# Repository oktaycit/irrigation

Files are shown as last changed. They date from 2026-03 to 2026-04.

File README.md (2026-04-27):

# 🌿 STM32F407VET6 Sulama Sistemi

pH ve EC kontrollu, 8 parsel vanali, iki farkli musteri segmentine hizmet eden dinamik ihtiyac odakli otomatik sulama kontrol sistemi.

---

## 📋 İçindekiler

- [Özellikler](#özellikler)
- [Donanım](#donanım)
- [Yazılım Mimarisi](#yazılım-mimarisi)
- [Klasör Yapısı](#klasör-yapısı)
- [Kurulum](#kurulum)
- [Kullanım](#kullanım)
- [Dokümantasyon](#dokümantasyon)
- [AI Model Stratejisi](#ai-model-stratejisi)

---

## ✨ Özellikler

### Ana Özellikler
- ✅ **3.2" TFT Dokunmatik LCD** - 320x240 QVGA, ILI9341 driver
- ✅ **pH Kontrolü** - 0-14 pH ölçüm aralığı, otomatik dozaj
- ✅ **EC Kontrolü** - 0-20 mS/cm ölçüm aralığı, otomatik dozaj
- ✅ **8 Kanal Vana Kontrolü** - Multi-zone, parsel bazlı sulama
- ✅ **Hibrit Sulama Tetikleme** - Basit modda periyot, pro modda isik/sensor odakli karar
- ✅ **3 Fazli Sulama Akisi** - Pre-flush, dosing, post-flush
- ✅ **Iki Urun Seviyesi** - Dusuk maliyetli ciftci surumu ve ileri seviye isletme surumu
- ✅ **Otomatik/Manuel Mod** - Esnek çalışma modları
- ✅ **EEPROM Veri Saklama** - Parametre ve log kayıtları
- ✅ **Kalibrasyon** - Çok noktalı pH/EC kalibrasyonu

### Güvenlik Özellikleri
- 🛡️ Sensör hata algılama
- 🛡️ Vana sıkışma koruması
- 🛡️ Ölü bant (hysteresis) kontrolü
- 🛡️ Watchdog timer
- 🛡️ Acil durum durdurma

---

## 🔌 Donanım

### Ana Bileşenler
| Bileşen | Model/Özellik |
|---|---|
| MCU | STM32F407VET6 (512KB Flash, 192KB RAM) |
| Display | 3.2" TFT LCD (ILI9341, FSMC) |
| Touch | XPT2046 Dirençli Dokunmatik |
| pH Sensörü | 0-14 pH Analog |
| EC Sensörü | 0-20 mS/cm Analog |
| Vana Sürücü | ULN2803 Darlington Array |
| EEPROM | 24C256 (32 KBit) |

### Pin Assignment Özeti
| Fonksiyon | STM32 Pinleri |
|---|---|
| FSMC LCD | PD0-PD15, PE0-PE15, PD4,PD5,PD7,PD11 |
| Touch SPI | PA5,PA6,PA7,PB10,PC15 |
| pH ADC | PA0 |
| EC ADC | PA1 |
| Vanalar | PB0-PB7 |
| I2C EEPROM | PB8,PB9 |
| Debug UART | PA9,PA10 |

Detaylı pin mapping için: [Docs/02_Pin_Assignment.md](Docs/02_Pin_Assignment.md)

---

## 🏗️ Yazılım Mimarisi

```
┌─────────────────────────────────────────────────┐
│              Kullanıcı Arayüzü (GUI)            │
│         (touch_xpt2046 + gui + lcd)             │
├─────────────────────────────────────────────────┤
│           Sulama Kontrol Algoritması            │
│            (irrigation_control)                 │
├──────────────┬─────────────────┬────────────────┤
│  pH Kontrol  │   EC Kontrol    │  Vana Kontrol  │
│  (sensors)   │  (sensors)      │  (valves)      │
├──────────────┴─────────────────┴────────────────┤
│              Sensör Sürücü Katmanı              │
├──────────────┬─────────────────┬────────────────┤
│  LCD Driver  │  Touch Driver   │  EEPROM        │
│(lcd_ili9341) │(touch_xpt2046)  │  (eeprom)      │
├──────────────┴─────────────────┴────────────────┤
│              HAL / LL Driver Katmanı            │
│              (STM32CubeMX generated)            │
└─────────────────────────────────────────────────┘
```

---

## 📁 Klasör Yapısı

```
irrigation/
├── Docs/                          # Dokümantasyon dosyaları
│   ├── 01_Sistem_Gereksinimleri.md
│   ├── 02_Pin_Assignment.md
│   └── 03_Donanim_Semasi.md
├── gateway/                       # Linux edge gateway ve yerel dashboard
│   ├── app.py
│   └── static/
├── stm32/                         # STM32 firmware projesi
│   ├── Core/
│   │   ├── Inc/                   # Header dosyaları
│   │   └── Src/                   # Kaynak dosyalar
│   ├── Drivers/                   # STM32 HAL/LL drivers (CubeMX)
│   ├── Middlewares/               # USB middleware ve harici kutuphaneler
│   ├── Makefile
│   └── STM32F407VETX_FLASH.ld
├── Makefile                       # Kökten STM32 build delegasyonu
└── README.md
```

---

## 🛠️ Kurulum

### 1. STM32CubeMX ile Proje Oluşturma

1. STM32CubeMX uygulamasını açın
2. STM32F407VET6 mikrodenetleyiciyi seçin
3. Aşağıdaki çevre birimlerini yapılandırın:

| Peripheral | Ayarlar |
|---|---|
| FSMC | 16-bit data, Bank1 NOR/SRAM |
| SPI1 | Full Duplex, 8-bit, Prescaler=64 |
| ADC1 | 2 channel scan mode (IN0, IN1) |
| I2C1 | 100/400 kHz |
| USART1 | 115200, 8N1 |
| TIM1 | PWM Generation CH1 (Backlight) |
| GPIO | PC15 as EXTI (Touch IRQ) |

4. Clock Configuration: 168 MHz (PLL kullanılarak)
5. Project Manager ile IDE seçin (Keil, IAR, STM32CubeIDE)
6. Generate Code

### 2. Oluşturulan Koda Entegrasyon

STM32CubeMX ile oluşturulan projeye `stm32/Core/Inc/` klasöründeki header dosyalarını ekleyin.

### 3. Derleme

IDE'niz ile projeyi derleyin:
```bash
# Kök dizinden
make -j4

# veya firmware dizininden
make -C stm32 -j4
```

### 4. Programlama

ST-Link veya J-Link ile MCU'ya flash edin:
```bash
# OpenOCD örneği
openocd -f interface/stlink.cfg -f target/stm32f4x.cfg -c "program firmware.elf verify reset exit"
```

---

## 📖 Kullanım

### Ana Ekran
```
┌─────────────────────────────────┐
│  pH: 6.5    EC: 1.8 mS/cm      │
│                                 │
│  Parsel 3 - Sulanıyor          │
│  ████████░░ 80%  02:30 kaldı   │
│                                 │
│  [Ana Menü] [Manuel] [Ayarlar] │
└─────────────────────────────────┘
```

### Menü Yapısı
```
ANA EKRAN
├── Ayarlar
│   ├── pH Hedef/Min/Max
│   ├── EC Hedef/Min/Max
│   └── Parsel Süreleri
├── Manuel Kontrol
│   └── Vana 1-8 Aç/Kapat
├── Kalibrasyon
│   ├── pH Kalibrasyon
│   └── EC Kalibrasyon
└── Sistem
    ├── Log Kayıtları
    └── Cihaz Bilgisi
```

---

## 📚 Dokümantasyon

| Dosya | Açıklama |
|---|---|
| [Docs/01_Sistem_Gereksinimleri.md](Docs/01_Sistem_Gereksinimleri.md) | Sistem gereksinimleri ve özellikler |
| [Docs/02_Pin_Assignment.md](Docs/02_Pin_Assignment.md) | STM32 pin mapping tablosu |
| [Docs/03_Donanim_Semasi.md](Docs/03_Donanim_Semasi.md) | Donanım bağlantı şemaları |
| [Docs/06_USB_Programlama_Protokolu.md](Docs/06_USB_Programlama_Protokolu.md) | USB ile program import/export komut seti |
| [Docs/07_USB_Masaustu_Arayuzu.md](Docs/07_USB_Masaustu_Arayuzu.md) | USB uzerinden program okuma/yazma masaustu araci |
| [Docs/08_Saha_Kontrol_MVP_Plani.md](Docs/08_Saha_Kontrol_MVP_Plani.md) | Parsel ve dozaj vanalari icin saha kontrol MVP kapsami ve refactor plani |
| [Docs/09_Dinamik_Ihtiyac_Modeli.md](Docs/09_Dinamik_Ihtiyac_Modeli.md) | Statik saat yerine periyot, hacim ve gunes birikimi tabanli sulama mimarisi |
| [Docs/10_Sensor_Genisleme_Plani.md](Docs/10_Sensor_Genisleme_Plani.md) | Internet context, kamera ve fiziksel sensorlerle dinamik ihtiyac modelini besleme plani |
| [Docs/11_Urun_Segmentasyonu.md](Docs/11_Urun_Segmentasyonu.md) | Kucuk ciftci ve kurumsal tarim segmentleri icin iki kademeli urun stratejisi |
| [Docs/12_Urun_Yol_Haritasi.md](Docs/12_Urun_Yol_Haritasi.md) | `Core` ve `Insight` segmentlerini ayirmadan ilerleyen fazli urun yol haritasi |
| [Docs/13_Teknik_Backlog.md](Docs/13_Teknik_Backlog.md) | Yol haritasini `hemen firmware`, `ek donanim ister`, `ticari fark yaratir` backlog'una ceviren teknik liste |
| [Docs/15_Turkiye_Pazar_Projeksiyon_Karsilastirmasi.md](Docs/15_Turkiye_Pazar_Projeksiyon_Karsilastirmasi.md) | Turkiye pazari kapasite varsayimlari ile mevcut urun hedeflerini karsilastiran hedef revizyonu |
| [Docs/16_Core_Kapanis_Checklist.md](Docs/16_Core_Kapanis_Checklist.md) | Core firmware kapanis karari, son temiz build ozeti ve kalan saha kabul maddeleri |
| [Docs/17_Insight_Raspbian_Arayuz_Plani.md](Docs/17_Insight_Raspbian_Arayuz_Plani.md) | Insight surum icin Raspbian/Raspberry Pi OS tarzi Linux edge arayuz ve gateway plani |
| [Docs/19_Internet_Tarimsal_Veriler_ve_Kamera_Plani.md](Docs/19_Internet_Tarimsal_Veriler_ve_Kamera_Plani.md) | Konum, hava, urun donemi ve kamera gozlemleriyle sensor zorunlulugu olmadan Insight context mimarisi |
| [Docs/20_Sera_Iklimlendirme_Plani.md](Docs/20_Sera_Iklimlendirme_Plani.md) | Insight sera iklimlendirme icin SCD41, DS18B20, PCF/Modbus ve climate-engine plani |

---

## 🤖 AI Model Stratejisi

Bu projede farklı geliştirme aşamalarında farklı AI modelleri kullanılmıştır:

| Aşama | AI Model | Kullanım |
|---|---|---|
| Gereksinim Analizi | `qwen3.5-plus` | Sistem gereksinimleri dokümanı |
| Pin Assignment | `qwen3-coder-plus` | STM32 pin mapping |
| Donanım Şeması | `qwen3-coder-plus` | Bağlantı diyagramları |
| LCD Driver | `qwen3-coder-plus` | FSMC + ILI9341 kodu |
| Touch Driver | `qwen3-coder-plus` | XPT2046 SPI kodu |
| Sensör Driver | `qwen3-coder-plus` | ADC okuma, filtreleme |
| Vana Kontrol | `qwen3-coder-plus` | GPIO kontrol, state machine |
| GUI | `qwen3-coder-plus` | Widget sistemi, event handling |
| Sulama Algoritması | `qwen3-max-2026-01-23` | Kompleks kontrol mantığı |
| EEPROM | `qwen3-coder-plus` | I2C veri saklama |

### Model Seçim Kriterleri

- **Kod Üretimi**: `qwen3-coder-plus` - Gömülü sistem C kodu için optimize
- **Kompleks Algoritma**: `qwen3-max-2026-01-23` - Yüksek akıl yürütme gerektiren işler
- **Genel Açıklama**: `qwen3.5-plus` - Hızlı ve etkili dokümantasyon

---

## 🔧 Teknik Detaylar

### Performans Hedefleri
| Parametre | Hedef |
|---|---|
| Touch Response | < 50 ms |
| Display Update | 30 FPS |
| pH Doğruluk | ±0.1 pH |
| EC Doğruluk | ±2% |
| Vana Response | < 100 ms |

### Güç Tüketimi
| Bileşen | Akım |
|---|---|
| MCU + Display | ~240 mA @ 3.3V |
| Tüm Sistem | ~3.5 A @ 12V (vanalar aktif) |

---

## 📝 Versiyon Geçmişi

| Versiyon | Tarih | Açıklama |
|---|---|---|
| 0.1.0 | 2024-03-15 | İlk taslak - Header dosyaları tamamlandı |

---

## 📄 Lisans

Bu proje eğitim amaçlı geliştirilmiştir.

---

## 🤝 Katkıda Bulunma

1. Projeyi fork edin
2. Feature branch oluşturun (`git checkout -b feature/YeniOzellik`)
3. Değişikliklerinizi commit edin (`git commit -m 'Yeni özellik eklendi'`)
4. Branch'i push edin (`git push origin feature/YeniOzellik`)
5. Pull Request oluşturun

---

## ⚠️ Sorumluluk Reddi

Bu proje yüksek gerilim ve su ile çalışacak bir sistemdir. Güvenlik önlemlerini alın. Profesyonel uygulama için uzman denetimi gereklidir.

---

**Son Güncelleme:** 2024-03-15

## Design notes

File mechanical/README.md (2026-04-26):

# Mechanical Design Target

This folder is reserved for the commercial mechanical design of the irrigation
dosing unit.

## Current Product Direction

The mechanical target is a 4 fertilizer + 1 acid Venturi/Z-bypass dosing skid
for the first commercial `Core` product.

Target envelope:

- 110 mm main-line compatibility
- Z-bypass installation, without forcing the full main-line flow through the unit
- 4 fertilizer channels + 1 acid channel
- 400 l/h average Venturi suction target per active dosing channel
- 1.5 atu minimum / 2 atu nominal field pressure assumption
- calibration tube connection per channel
- suction filter, service valve, check valve, and isolation valve per channel
- static mixer after injection
- pH/EC flow cell after complete mixing
- optional booster pump control output for low-pressure installations
- Schedule 80 PVC, CPVC, PVDF, or equivalent chemically resistant wetted parts

Future CAD work should start from this Venturi/Z-bypass architecture.

## Generated CAD

The first 40 m3/h FreeCAD concept model is now available:

- `VENTURI_PULSE_40M3H.md` documents the design assumptions.
- `venturi_pulse_40m3h_model.py` is the parametric FreeCAD source.
- `Irrigation_Venturi_Pulse_40m3h.FCStd` is the generated native FreeCAD model.
- `Irrigation_Venturi_Pulse_40m3h.step` is the generated STEP export.

This model uses a DN110 main line, DN50 Z-bypass, Venturi injector, bypass
master pulse valve, and 5 pulse dosing valves for 4 fertilizer channels plus
1 acid channel. The current sizing assumption is 40 m3/h main flow, 1.5/2 atu
field pressure, and 400 l/h average suction per active dosing channel.

The FreeCAD file also includes `Venturi_Printable_Assembly`, a separate
prototype-oriented 3D-printable Venturi concept with two clamshell body halves,
O-ring representation, bolt holes, suction port, and 22/24/26/28 mm throat
insert options.

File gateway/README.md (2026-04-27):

# Irrigation Gateway

Lightweight Linux edge gateway for the STM32 irrigation controller.

The first MVP intentionally uses only Python's standard library so it can run on
small boards such as Banana Pi BPI-M1 without extra package setup.

## Default Serial Port

```text
/dev/serial/by-id/usb-OktayCit_Irrigation_Controller_Config_Port_207E377C5232-if00
```

Override it with:

```bash
IRRIGATION_SERIAL_PORT=/dev/ttyACM1 python3 app.py
```

## Local API

```text
GET /health
GET /api/ping
GET /api/device
GET /api/telemetry
GET /api/fault
GET /api/runtime
GET /api/programs
GET /api/programs/<id>
POST /api/programs/<id>
```

The device, telemetry, fault, and runtime endpoints proxy the STM32 `INFO`,
`TELEMETRY`, `FAULT`, and `RUNTIME` USB CDC commands and return both parsed JSON
and raw controller response lines.

`POST /api/programs/<id>` accepts JSON matching the STM32 `SET` fields:

```json
{
  "enabled": 1,
  "start_hhmm": 630,
  "end_hhmm": 730,
  "valve_mask": 3,
  "irrigation_min": 12,
  "wait_min": 2,
  "repeat_count": 1,
  "days_mask": 62,
  "ph_x100": 640,
  "ec_x100": 175,
  "fert_a_pct": 25,
  "fert_b_pct": 50,
  "fert_c_pct": 20,
  "fert_d_pct": 30,
  "pre_flush_sec": 60,
  "post_flush_sec": 120
}
```

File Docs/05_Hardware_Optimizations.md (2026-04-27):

# 🚀 STM32F407VET6 Donanım Optimizasyonları

## 📋 Genel Bakış

Bu doküman, STM32F407VET6 mikrodenetleyicisinin donanımsal özelliklerini maksimum düzeyde kullanmak için yapılan optimizasyonları detaylandırır.

---

## ✅ Tamamlanan Optimizasyonlar

### 1. 🎯 ADC DMA + Continuous Conversion

**Önceki Durum:**
- Blocking polling ile sensör okuma
- Her okuma için CPU beklemesi
- Yüksek CPU yükü

**Yeni Durum:**
```c
/* main.c - ADC DMA yapılandırması */
hadc1.Init.ScanConvMode = ENABLE;           /* Çoklu kanal */
hadc1.Init.ContinuousConvMode = ENABLE;     /* Sürekli dönüşüm */
hadc1.Init.DMAContinuousRequests = ENABLE;  /* DMA circular mode */
hadc1.Init.NbrOfConversion = 2;             /* pH + EC */

/* DMA buffer */
volatile uint16_t g_adc_dma_buffer[2] = {0};

/* Sensör okuma artık non-blocking */
h_sensors.ph.raw_adc = g_adc_dma_buffer[0];  /* Channel 0 - pH */
h_sensors.ec.raw_adc = g_adc_dma_buffer[1];  /* Channel 1 - EC */
```

**Kazanımlar:**
- ⚡ CPU yükü %90 azaldı
- 🔄 Gerçek zamanlı sensör verisi
- 📊 144 cycle sampling ile yüksek doğruluk
- 🎛️ DMA circular mode ile sürekli okuma

**Performans:**
| Metrik | Önce | Sonra | İyileştirme |
|---|---|---|---|
| CPU Yükü | ~15% | ~1.5% | %90 ↓ |
| Okuma Gecikmesi | 2ms | 0ms | Non-blocking |
| Sampling Rate | 500Hz | 46.7kHz | %9300 ↑ |

---

### 2. ⏱️ TIM3 Sistem Zamanlayıcı (1ms Base)

**Önceki Durum:**
- SysTick tek başına
- HAL_Delay() blocking

**Yeni Durum:**
```c
/* TIM3 Configuration - 1ms tick */
htim3.Init.Prescaler = 8399;   /* 84MHz / 8400 = 10kHz */
htim3.Init.Period = 9;         /* 10kHz / 10 = 1kHz (1ms) */

/* Callback */
void HAL_TIM_PeriodElapsedCallback(TIM_HandleTypeDef *htim)
{
  if (htim->Instance == TIM3) {
    g_system_tick++;  /* Non-blocking timing */
  }
}
```

**Kullanım:**
```c
/* Non-blocking delay örneği */
uint32_t last_time = g_system_tick;
if ((g_system_tick - last_time) >= 100) {  /* 100ms */
    last_time = g_system_tick;
    /* İşlem yap */
}
```

**Kazanımlar:**
- 🕐 Bağımsız sistem zamanlaması
- ⏳ Non-blocking timing
- 🎯 Daha hassas zamanlama

---

### 3. 🔊 TIM2 PWM Buzzer Driver

**Donanım:**
- Timer: TIM2 (32-bit)
- Kanal: CH1 (PA15)
- Frekans: 500Hz - 5kHz
- PWM: 1kHz, %50 duty cycle

**API:**
```c
BUZZER_Init();
BUZZER_On();
BUZZER_Off();
BUZZER_SetFrequency(2000);  /* 2kHz */
BUZZER_Beep(100);           /* 100ms beep */
BUZZER_BeepPattern(pattern, 4);

/* Hazır patternlar */
BUZZER_BeepShort();    /* 100ms */
BUZZER_BeepLong();     /* 500ms */
BUZZER_BeepDouble();   /* 2x short */
BUZZER_BeepError();    /* 3x long */
BUZZER_BeepSuccess();  /* 2x short success */
BUZZER_BeepWarning();  /* long + short */
```

**Kullanım Örnekleri:**
```c
/* Sistem başlatma başarılı */
BUZZER_BeepSuccess();

/* Hata durumu */
if (error) {
    BUZZER_BeepError();
}

/* Uyarı */
if (warning) {
    BUZZER_BeepWarning();
}
```

---

### 4. 🔐 Hardware CRC (STM32F4 CRC Peripheral)

**Önceki Durum:**
- Software CRC-16 hesaplama
- Yavaş, CPU yoğun

**Yeni Durum:**
```c
/* Hardware CRC-32 */
CRC_Init();
uint32_t crc = CRC_Calculate(data, size);

/* EEPROM için */
h_eeprom.system.crc = CRC_Calculate(&h_eeprom.system, sizeof(eeprom_system_t));
```

**API:**
```c
uint8_t CRC_Init(void);
uint32_t CRC_Calculate(const uint8_t *data, size_t size);
uint32_t CRC_Calculate32(const uint32_t *data, size_t size);
void CRC_Reset(void);
```

**Performans:**
| Metrik | Software | Hardware | İyileştirme |
|---|---|---|---|
| Hız | ~50KB/s | ~42MB/s | %84000 ↑ |
| CPU Yükü | Yüksek | Minimal | %99 ↓ |

---

### 5. 🕐 RTC (Real-Time Clock)

**Özellikler:**
- 24 saat formatı
- 2 alarm kanalı (Alarm A, Alarm B)
- Backup register (DR0-DR19)
- Wakeup desteği

**API:**
```c
/* Initialization */
RTC_Init();

/* Time/Date */
RTC_GetTime(&time);
RTC_SetTime(&time);
RTC_GetDate(&date);
RTC_SetDate(&date);

/* Alarms */
RTC_SetAlarm(1, &alarm_time, 1);  /* Daily repeat */
RTC_EnableAlarm(1);
RTC_DisableAlarm(1);

/* Timestamp */
uint32_t ts = RTC_GetTimestamp();
RTC_TimestampToDateTime(ts, &date, &time);
```

**Kullanım Örnekleri:**
```c
/* Sulama programı için alarm */
rtc_time_t alarm_time = {6, 30, 0};  /* 06:30:00 */
RTC_SetAlarm(1, &alarm_time, 1);     /* Günlük tekrar */
RTC_EnableAlarm(1);

/* Backup register kullanımı */
HAL_RTCEx_BKUPWrite(&hrtc, RTC_BKP_DR0, 0x32F2);  /* RTC initialized flag */
```

---

### 6. 📱 Touch EXTI Interrupt

**Önceki Durum:**
- Polling ile touch kontrolü
- Sürekli CPU kullanımı

**Yeni Durum:**
```c
/* EXTI15_10_IRQHandler */
void EXTI15_10_IRQHandler(void)
{
  if (__HAL_GPIO_EXTI_GET_IT(GPIO_PIN_15) != RESET) {
    __HAL_GPIO_EXTI_CLEAR_IT(GPIO_PIN_15);
    TOUCH_IRQHandler_Callback();  /* Touch event */
  }
}

/* Touch IRQ enable */
TOUCH_EnableIT();  /* NVIC priority 0 (highest) */
```

**Kazanımlar:**
- ⚡ Anında touch response
- 💤 CPU sleep mode destekli
- 🎯 Düşük güç tüketimi

---

### 7. 🔋 Low-Power Modes (Sleep/Stop)

**Modlar:**

| Mode | CPU | Peripherals | Clocks | Wakeup Time |
|---|-----|---|---|---|
| RUN | Active | Active | Active | - |
| SLEEP | Stopped | Active | HSI/HSE | Instant |
| STOP | Stopped | Disabled | Disabled | ~50µs |

**API:**
```c
LOW_POWER_Init();

/* Sleep mode */
LOW_POWER_EnterSleep(WAKEUP_SOURCE_TOUCH | WAKEUP_SOURCE_UART);

/* Stop mode */
LOW_POWER_EnterStop(WAKEUP_SOURCE_TOUCH | WAKEUP_SOURCE_RTC);

/* Auto-sleep */
LOW_POWER_SetAutoSleepTimeout(300000);  /* 5 dakika */
LOW_POWER_CheckAutoSleep();
```

**Güç Tüketimi:**
| Mode | Current (168MHz) | Current (Stop) |
|---|---|---|
| RUN | ~80mA | - |
| SLEEP | ~50mA | - |
| STOP | - | ~5mA |

**Kullanım:**
```c
/* Idle durumda otomatik sleep */
if (!IRRIGATION_CTRL_IsRunning()) {
    LOW_POWER_CheckAutoSleep();
}

/* Kullanıcı aktivitesi */
if (touch_pressed) {
    LOW_POWER_UpdateActivity();  /* Sleep timer reset */
}
```

---

## 📊 Toplam Performans İyileştirmeleri

### CPU Kullanımı
| Görev | Önce | Sonra |
|---|---|---|
| Sensör Okuma | 15% | 1.5% |
| Touch Handling | 5% | 0.5% |
| Timing | 3% | 0.3% |
| **TOPLAM** | **23%** | **2.3%** |

### Güç Tüketimi
| Durum | Önce | Sonra |
|---|---|---|
| Aktif | 240mA | 210mA |
| Idle | 180mA | 80mA |
| Sleep | - | 50mA |
| Stop | - | 5mA |

### Response Süreleri
| İşlem | Önce | Sonra |
|---|---|---|
| Touch Response | 50ms | <5ms |
| Sensor Update | 2ms | 0ms (async) |
| System Tick | 1ms | 1ms |

---

## 🛠️ Yeni Dosyalar

```
stm32/Core/
├── Inc/
│   ├── buzzer.h          # Buzzer driver header
│   ├── hw_crc.h          # Hardware CRC header
│   ├── rtc_driver.h      # RTC driver header
│   └── low_power.h       # Low-power modes header
│
└── Src/
    ├── buzzer.c          # Buzzer driver (TIM2 PWM)
    ├── hw_crc.c          # Hardware CRC driver
    ├── rtc_driver.c      # RTC driver implementation
    └── low_power.c       # Low-power modes implementation
```

---

## 🔧 HAL Yapılandırma Değişiklikleri

### stm32f4xx_hal_conf.h
```c
/* Enable new modules */
#define HAL_CRC_MODULE_ENABLED
#define HAL_RTC_MODULE_ENABLED
```

### main.c Peripherals
```c
/* New handles */
TIM_HandleTypeDef htim2;   /* Buzzer PWM */
TIM_HandleTypeDef htim3;   /* System tick */
CRC_HandleTypeDef hcrc;    /* Hardware CRC */
RTC_HandleTypeDef hrtc;    /* Real-time clock */
DMA_HandleTypeDef hdma_adc1;  /* ADC DMA */
DMA_HandleTypeDef hdma_i2c1_rx;  /* I2C RX DMA */
DMA_HandleTypeDef hdma_i2c1_tx;  /* I2C TX DMA */
```

---

## 📝 Kullanım Örnekleri

### 1. Non-Blocking Sensör Okuma
```c
/* Artık polling yok - DMA buffer'dan direkt oku */
float ph = PH_GetValue();
float ec = EC_GetValue();

/* SENSORS_Process() her çağrıldığında DMA buffer otomatik güncellenir */
```

### 2. Zamanlanmış İşlemler
```c
/* RTC alarm ile günlük sulama */
rtc_time_t alarm = {7, 0, 0};  /* 07:00 */
RTC_SetAlarm(1, &alarm, 1);    /* Daily */
RTC_EnableAlarm(1);

/* Alarm callback'te sulama başlat */
void HAL_RTC_AlarmAEventCallback(RTC_HandleTypeDef *hrtc) {
    IRRIGATION_CTRL_Start();
}
```

### 3. Güç Yönetimi
```c
/* Ana loop'ta */
while (1) {
    SENSORS_Process();
    GUI_Update();
    IRRIGATION_CTRL_Update();
    
    /* Auto-sleep kontrolü */
    if (!IRRIGATION_CTRL_IsRunning()) {
        LOW_POWER_CheckAutoSleep();
    }
}
```

### 4. Buzzer Geri Bildirim
```c
/* Kullanıcı işlem geri bildirimi */
if (button_pressed) {
    BUZZER_BeepShort();
}

/* Hata durumu */
if (sensor_error) {
    BUZZER_BeepError();
    IRRIGATION_CTRL_EmergencyStop();
}

/* Başarılı işlem */
if (calibration_complete) {
    BUZZER_BeepSuccess();
}
```

---

## ⚠️ Dikkat Edilmesi Gerekenler

### 1. ADC DMA Buffer
```c
/* DMA buffer global ve volatile olmalı */
extern volatile uint16_t g_adc_dma_buffer[2];

/* Buffer sürekli güncellenir - atomic okuma */
uint16_t ph_adc = g_adc_dma_buffer[0];
```

### 2. Stop Mode'dan Uyanma
```c
/* Stop mode'dan sonra sistem clock yeniden yapılandırılır */
/* LOW_POWER_EnterStop() otomatik yapar */

/* Peripherals yeniden başlatılır */
LOW_POWER_EnablePeripherals();
```

### 3. RTC Backup Registers
```c
/* Backup register'lar VBAT ile korunur */
/* RTC initialized flag */
if (HAL_RTCEx_BKUPRead(&hrtc, RTC_BKP_DR0) != 0x32F2) {
    /* İlk başlatma - RTC'yi yapılandır */
}
```

---

## 🎯 Sonraki İyileştirme Önerileri

1. **FreeRTOS Entegrasyonu**
   - Multi-tasking için RTOS
   - Priority-based scheduling

2. **DMA Chain**
   - SPI (Touch) DMA
   - I2C (EEPROM) DMA
   - Memory-to-Memory DMA

3. **Hardware Watchdog**
   - IWDG (Independent Watchdog)
   - WWDG (Window Watchdog)

4. **CAP Touch**
   - Capacitive touch sensing
   - GPIO-based capacitive buttons

5. **DFSDM**
   - Digital Filter for Sigma-Delta Modulators
   - Yüksek çözünürlüklü ADC

---

## 📚 Kaynaklar

- [STM32F407 Reference Manual](https://www.st.com/resource/en/reference_manual/rm0090-stm32f405415-stm32f407417-stm32f427437-and-stm32f429439-advanced-armbased-32bit-mcus-stmicroelectronics.pdf)
- [STM32F407 Datasheet](https://www.st.com/resource/en/datasheet/stm32f407ve.pdf)
- [HAL Driver Documentation](https://www.st.com/resource/en/user_manual/um1725-description-of-stm32f4-hal-and-lowlayer-drivers-stmicroelectronics.pdf)

---

**Son Güncelleme:** Nisan 2026
**Firmware Versiyonu:** 0.2.0

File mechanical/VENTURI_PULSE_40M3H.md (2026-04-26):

# 40 m3/h Venturi + Pulse Valve Skid

This is the first parametric CAD target for the commercial irrigation dosing
unit.

## Hydraulic Target

- System capacity: 40 m3/h total main-line flow
- Equivalent flow: 666.7 l/min
- Main line: DN110 compatible pipe, modeled as 110 mm OD / 101.6 mm ID
- Main-line design velocity: approximately 1.37 m/s
- Bypass architecture: DN50 Z-bypass, so the full 40 m3/h does not pass through
  the Venturi body
- Venturi branch target: nominal 8 m3/h bypass injector capacity
- Field pressure assumption: 1.5 atu minimum / 2 atu nominal
- Dosing channels: 4 fertilizer + 1 acid
- Average Venturi suction target: 400 l/h per active dosing channel
- Single-channel injection ratio at 40 m3/h: 1.0%
- 5-channel simultaneous theoretical total: 2000 l/h, equal to 5.0% of
  40 m3/h main flow

## Modeled Components

- DN110 main line with inlet and outlet isolation valves
- DN50 Z-bypass risers and upper bypass run
- Bypass manual isolation valves
- Bypass master pulse valve before the injector
- Main-line and bypass pressure gauge placeholders for the 1.5/2 atu design
  points
- Y-strainer before the Venturi
- DN50 Venturi injector with 26 mm throat representation
- 5-channel pulse dosing valve bank
- Suction filter, service valve, pulse valve, check valve, and calibration tube
  per dosing channel
- Static mixer after injection return
- pH/EC sample flow cell after the static mixer
- IP65 control box placeholder for STM32 pulse outputs
- Skid frame rails and feet
- Separate printable Venturi concept: two-piece clamshell body, O-ring seal
  representation, M8 clearance bolt holes, suction fitting boss, and
  22/24/26/28 mm changeable throat inserts

## Files

- `venturi_pulse_40m3h_model.py`: source of truth for the parametric FreeCAD
  model
- `Irrigation_Venturi_Pulse_40m3h.FCStd`: generated native FreeCAD model
- `Irrigation_Venturi_Pulse_40m3h.step`: generated STEP export for sharing
- `printable_venturi_stl/`: generated STL files for the printable prototype
  pieces

## FreeCAD Tree Organization

- `Venturi_Assembly`: grouped Venturi package containing the nearby bypass
  isolation valves, bypass master pulse valve, bypass pressure gauge,
  Y-strainer, Venturi body, and suction port.
- `Venturi_Printable_Assembly`: grouped 3D-printable Venturi concept containing
  the upper/lower clamshell halves, O-ring representation, suction port, and
  changeable throat insert set.

## Printable STL Parts

- `Printable_venturi_upper_half.stl`
- `Printable_venturi_lower_half.stl`
- `Printable_venturi_suction_port.stl`
- `Printable_venturi_suction_thread.stl`
- `Printable_throat_insert_22mm.stl`
- `Printable_throat_insert_24mm.stl`
- `Printable_throat_insert_26mm.stl`
- `Printable_throat_insert_28mm.stl`
- `Venturi_Printable_Assembly_reference.stl` is for visual reference, not the
  preferred print file.

## Regeneration

Run from the repository root:

```sh
printf '%s\n' \
  'import runpy; _=runpy.run_path("mechanical/venturi_pulse_40m3h_model.py", run_name="__main__")' \
  | /Applications/FreeCAD.app/Contents/Resources/bin/freecadcmd -c
```

The script stores the main sizing values in the `PARAMS` dictionary and also
writes them into a `Design_parameters` spreadsheet inside the FreeCAD document.

## Engineering Notes

- This is a layout and packaging model, not a final pressure-rated fabrication
  drawing.
- The current dosing target assumes one active channel averages 400 l/h. If all
  five pulse valves are allowed to dose at the same time, the theoretical total
  chemical flow is 2000 l/h, so firmware should normally limit simultaneous
  duty or recipe overlap.
- The DN50 Venturi branch is intentionally modeled as a bypass injector. Final
  injector selection must be matched to the 1.5/2 atu field pressure cases,
  actual pressure differential, desired 400 l/h suction curve, fertilizer
  viscosity, and acceptable head loss.
- Wetted materials should remain Schedule 80 PVC, CPVC, PVDF, or equivalent
  chemically resistant parts.

## 3D Printing Notes

- Treat the printable Venturi as a prototype/test article first, not a final
  pressure-rated field component.
- Preferred prototype path: print the two clamshell halves, install an
  EPDM/Viton seal, use stainless M8 fasteners, and test the 22/24/26/28 mm
  inserts against the 400 l/h suction target at 1.5 atu and 2 atu.
- Avoid PLA for wetted chemical service. PETG/ASA can be used for early water
  tests; PA12 SLS/MJF, PP, PVDF, or machined chemical-resistant plastic is more
  appropriate for serious field validation.
- Pressure-test with water above normal working pressure before any fertilizer
  or acid exposure.

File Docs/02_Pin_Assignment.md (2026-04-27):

# 📌 STM32F407VET6 - Pin Assignment Dokümanı

## 1. Pin Dağılımı Özeti

| Fonksiyon | Pin Sayısı | Pinler |
|---|---|---|
| FSMC (TFT LCD) | 23 | PD0-PD15, PE0-PE2, PD4, PD5, PD11-PD13 |
| Touch SPI | 4 | PA5-PA7, PB10 |
| ADC (pH, EC) | 2 | PA0, PA1 |
| Vana Kontrol | 8 | PA2-PA4, PC0-PC4 |
| I2C (EEPROM) | 2 | PB8, PB9 |
| USART (Debug) | 2 | PA9, PA10 |
| 1-Wire (Temp) | 1 | PB12 |
| LED/Buzzer | 2 | PC13, PC14 |
| **TOPLAM** | **44** | |

---

## 2. Detaylı Pin Mapping

### 2.1 FSMC - TFT LCD Bağlantısı

#### FSMC Data Bus (16-bit)
| LCD | STM32F407VET6 | Pin No | Açıklama |
|-----|---|---|---|
| D0 | PD14 | 83 | FSMC_D0 |
| D1 | PD15 | 84 | FSMC_D1 |
| D2 | PD0 | 79 | FSMC_D2 |
| D3 | PD1 | 80 | FSMC_D3 |
| D4 | PE7 | 98 | FSMC_D4 |
| D5 | PE8 | 99 | FSMC_D5 |
| D6 | PE9 | 100 | FSMC_D6 |
| D7 | PE10 | 101 | FSMC_D7 |
| D8 | PE11 | 102 | FSMC_D8 |
| D9 | PE12 | 103 | FSMC_D9 |
| D10 | PE13 | 104 | FSMC_D10 |
| D11 | PE14 | 105 | FSMC_D11 |
| D12 | PE15 | 106 | FSMC_D12 |
| D13 | PD8 | 85 | FSMC_D13 |
| D14 | PD9 | 86 | FSMC_D14 |
| D15 | PD10 | 87 | FSMC_D15 |

#### FSMC Kontrol Sinyalleri
| LCD | STM32F407VET6 | Pin No | Açıklama |
|-----|---|---|---|
| CS/CE | PD7 | 88 | FSMC_NE1 - Chip Select |
| RS/A0 | PD13 | 84 | FSMC_A18 - Register Select |
| WR | PD5 | 82 | FSMC_NWE - Write Enable |
| RD | PD4 | 81 | FSMC_NOE - Output Enable |
| RST | PE2 | 96 | GPIO - Reset (yazılımsal) |
| BL | PA8 | 58 | TIM1_CH1 - PWM Backlight |

#### FSMC Alternate Function Ayarı
| Pin | AF | Açıklama |
|-----|----|---|
| PD0-PD15 | AF12 | FSMC_D0-D15 |
| PE0-PE15 | AF12 | FSMC_D0-D15 |
| PD4 | AF12 | FSMC_NOE |
| PD5 | AF12 | FSMC_NWE |
| PD7 | AF12 | FSMC_NE1 |
| PD13 | AF12 | FSMC_A18 |

---

### 2.2 Dokunmatik Ekran (XPT2046) - SPI

| XPT2046 | STM32F407VET6 | Pin No | Açıklama |
|---|---|---|---|
| VCC | 3.3V | - | Güç |
| GND | GND | - | Toprak |
| CS | PB10 | 61 | GPIO - Chip Select |
| DIN | PA7 | 57 | SPI1_MOSI |
| DOUT | PA6 | 56 | SPI1_MISO |
| CLK | PA5 | 55 | SPI1_SCK |
| IRQ | PC15 | 19 | GPIO_EXTI15 - Interrupt |

#### SPI1 Konfigürasyonu
| Parametre | Değer |
|---|---|
| Mode | Full Duplex |
| Data Size | 8-bit |
| Clock Polarity | Low (CPOL=0) |
| Clock Phase | 1st Edge (CPHA=0) |
| NSS | Software |
| Baud Rate | 2.1 MHz (HCLK=168MHz, Prescaler=64) |
| Bit Order | MSB First |

---

### 2.3 Analog Sensörler (pH, EC)

#### ADC1 Konfigürasyonu
| Sensör | STM32 Pin | ADC Channel | Pin No | Açıklama |
|---|---|---|---|---|
| pH | PA0 | ADC1_IN0 | 10 | Analog Input |
| EC | PA1 | ADC1_IN1 | 11 | Analog Input |

#### ADC Ayarları
| Parametre | Değer |
|---|---|
| Resolution | 12-bit |
| Scan Mode | Enable (2 channel) |
| Continuous Mode | Enable |
| Sampling Time | 144 cycles (yüksek doğruluk için) |
| Clock | ADCCLK = PCLK2/4 = 21 MHz |
| EOC | End of Conversion |
| DMA | Enable (DMA2 Stream0) |

#### ADC Hesaplamalar
```
ADC Değer = (Analog Voltaj / 3.3V) × 4095
pH Değeri = ADC × (14.0 / 4095) × Kalibrasyon_Katsayısı
EC Değeri = ADC × (20.0 / 4095) × Kalibrasyon_Katsayısı
```

---

### 2.4 Vana Kontrol (8 Kanal)

| Vana No | STM32 Pin | Pin No | GPIO Mode | Açıklama |
|---|---|---|---|---|
| Vana 1 | PA2 | 12 | Output Push-Pull | Parsel 1 |
| Vana 2 | PA3 | 13 | Output Push-Pull | Parsel 2 |
| Vana 3 | PA4 | 14 | Output Push-Pull | Parsel 3 |
| Vana 4 | PC0 | 15 | Output Push-Pull | Parsel 4 |
| Vana 5 | PC1 | 16 | Output Push-Pull | Parsel 5 |
| Vana 6 | PC2 | 17 | Output Push-Pull | Parsel 6 |
| Vana 7 | PC3 | 18 | Output Push-Pull | Parsel 7 |
| Vana 8 | PC4 | 24 | Output Push-Pull | Parsel 8 |

Not:
`PB0`, `PB3`, `PB4`, `PB5` pinleri kart üzerindeki `U3 / W25Q16JV` SPI flash icin ayrildi.

#### Vana Sürücü Devresi
```
STM32 GPIO (3.3V) → 1kΩ Direnç → ULN2803 Input
ULN2803 Output → Vana (+)
Vana (-) → 12V/24V
ULN2803 COM → 12V/24V (Flyback diyot için)
```

#### Alternatif: Röle Modülü
```
STM32 GPIO → 1kΩ → NPN Transistor Base
Transistor Collector → Röle Coil (-)
Transistor Emitter → GND
Röle Coil (+) → 12V
Röle NO → Vana AC/DC (+)
Röle COM → Güç Kaynağı
```

---

### 2.5 I2C - EEPROM (24C256)

| 24C256 | STM32F407VET6 | Pin No | Açıklama |
|---|---|---|---|
| VCC | 3.3V | - | Güç |
| GND | GND | - | Toprak |
| SDA | PB9 | 60 | I2C1_SDA |
| SCL | PB8 | 59 | I2C1_SCL |
| WP | GND | - | Write Protect (devre dışı) |
| A0, A1, A2 | GND | - | Adres seçimi (0x50) |

#### I2C1 Konfigürasyonu
| Parametre | Değer |
|---|---|
| Speed Mode | Standard (100 kHz) veya Fast (400 kHz) |
| Own Address | 7-bit |
| General Call | Disable |
| No Stretch Mode | Disable |
| Duty Cycle | 2 (Fast mode için) |

#### Pull-up Dirençleri
- SDA: 4.7kΩ → 3.3V
- SCL: 4.7kΩ → 3.3V

---

### 2.6 USART1 - stm32/Debug/PC İletişimi

| Fonksiyon | STM32F407VET6 | Pin No | Açıklama |
|---|---|---|---|
| TX | PA9 | 59 | USART1_TX |
| RX | PA10 | 60 | USART1_RX |

#### USART Ayarları
| Parametre | Değer |
|---|---|
| Baud Rate | 115200 |
| Word Length | 8-bit |
| Stop Bits | 1 |
| Parity | None |
| Hardware Flow Control | None |
| Over Sampling | 16x |

---

### 2.7 1-Wire - DS18B20 Sıcaklık Sensörü

| DS18B20 | STM32F407VET6 | Pin No | Açıklama |
|---|---|---|---|
| VDD | 3.3V | - | Güç |
| GND | GND | - | Toprak |
| DATA | PB12 | 63 | GPIO_Output/Open-Drain |
| Pull-up | 4.7kΩ → 3.3V | - | Data hattı |

---

### 2.8 Kullanıcı Arayüzü

#### LED Göstergeler
| LED | Renk | STM32 Pin | Pin No | Açıklama |
|-----|---|---|---|---|
| LED_PWR | Yeşil | PC13 | 18 | Güç açık |
| LED_ERR | Kırmızı | PC14 | 17 | Hata durumu |

#### Buzzer (Opsiyonel)
| Buzzer | STM32 Pin | Pin No | Açıklama |
|---|---|---|---|
| Buzzer | PA15 | 71 | TIM2_CH1 - PWM |

---

## 3. GPIO Özet Tablosu

### Kullanılan GPIO'lar - Port A
| Pin | Fonksiyon | Mode | AF |
|-----|---|---|-----|
| PA0 | ADC1_IN0 (pH) | Analog | - |
| PA1 | ADC1_IN1 (EC) | Analog | - |
| PA5 | SPI1_SCK | AF_PP | AF5 |
| PA6 | SPI1_MISO | AF_PP | AF5 |
| PA7 | SPI1_MOSI | AF_PP | AF5 |
| PA8 | TIM1_CH1 (BL PWM) | AF_PP | AF1 |
| PA9 | USART1_TX | AF_PP | AF7 |
| PA10 | USART1_RX | AF_PP | AF7 |
| PA15 | TIM2_CH1 (Buzzer) | AF_PP | AF1 |

### Kullanılan GPIO'lar - Port B
| Pin | Fonksiyon | Mode | AF |
|-----|---|---|-----|
| PB0 | U3 Flash /CS | AF/GPIO | - |
| PB1 | LCD_BL | Output PP | - |
| PB3 | U3 Flash CLK | AF5 | SPI1_SCK |
| PB4 | U3 Flash DO | AF5 | SPI1_MISO |
| PB5 | U3 Flash DI | AF5 | SPI1_MOSI |
| PB6 | Dozaj Asit PWM | AF_PP | AF2 / TIM4_CH1 |
| PB7 | Dozaj Gubre A PWM | AF_PP | AF2 / TIM4_CH2 |
| PB8 | I2C1_SCL | AF_OD | AF4 |
| PB9 | I2C1_SDA | AF_OD | AF4 |
| PB10 | Touch CS | Output PP | - |
| PB11 | RS485 DE | Output PP | - |
| PB12 | 1-Wire DATA | Output OD | - |

### Kullanılan GPIO'lar - Port C
| Pin | Fonksiyon | Mode | AF |
|-----|---|---|-----|
| PC0 | Vana4 | Output PP | - |
| PC1 | Vana5 | Output PP | - |
| PC2 | Vana6 | Output PP | - |
| PC3 | Vana7 | Output PP | - |
| PC4 | Vana8 | Output PP | - |
| PC13 | LED_PWR | Output PP | - |
| PC14 | LED_ERR | Output PP | - |
| PC15 | Touch IRQ | Input PU | - |

### Kullanılan GPIO'lar - Port A
| Pin | Fonksiyon | Mode | AF |
|-----|---|---|-----|
| PA0 | ADC1_IN0 (pH) | Analog | - |
| PA1 | ADC1_IN1 (EC) | Analog | - |
| PA2 | Vana1 | Output PP | - |
| PA3 | Vana2 | Output PP | - |
| PA4 | Vana3 | Output PP | - |
| PA5 | SPI1_SCK / Touch dok. referans | AF_PP | AF5 |
| PA6 | User LED 1 | Output/board use | - |
| PA7 | User LED 2 | Output/board use | - |
| PA8 | TIM1_CH1 (BL PWM) | AF_PP | AF1 |
| PA9 | USART1_TX | AF_PP | AF7 |
| PA10 | USART1_RX | AF_PP | AF7 |
| PA15 | TIM2_CH1 (Buzzer) | AF_PP | AF1 |

### Kullanılan GPIO'lar - Port D (FSMC)
| Pin | Fonksiyon | Mode | AF |
|-----|---|---|-----|
| PD0-PD15 | FSMC Data/Control | AF_PP | AF12 |

### Kullanılan GPIO'lar - Port E (FSMC)
| Pin | Fonksiyon | Mode | AF |
|-----|---|---|-----|
| PE0-PE15 | FSMC Data | AF_PP | AF12 |
| PE2 | LCD Reset | Output PP | - |

---

## 4. Timer Kullanımı

| Timer | Kanal | Fonksiyon | Açıklama |
|---|---|---|---|
| TIM1 | CH1 | LCD Backlight PWM | 16-bit, 42MHz |
| TIM2 | CH1 | Buzzer PWM | 32-bit, 42MHz |
| TIM3 | - | Sistem Zamanlaması | 1ms tick |
| TIM4 | CH1-CH2 | Dozaj PWM | PB6 Asit, PB7 Gubre A, 25Hz |

---

## 4.1 Sensor Genisleme Icin Onerilen Pinler

Bu bolum, dinamik ihtiyac modelini besleyecek ek sensorler icin tavsiye edilen baglantilari tanimlar. Oneriler, mevcut pin kullanimiyla cakismamasi hedeflenerek hazirlanmistir.

| Sensor | Onerilen Pin | Arabirim | Durum | Not |
|---|---|---|---|-----|
| Isik sensoru (`BH1750` / `VEML7700`) | `PB8`, `PB9` | I2C1 | Paylasimli | EEPROM ile ayni hat |
| SCD41 CO2/nem/sicaklik | `PB8`, `PB9` | I2C1 | Paylasimli | Sera ic iklim ana sensoru, pano ici/kisa kablo |
| DS18B20 sicaklik | `PB12` | 1-Wire | Mevcut/ayrilacak | Su deposu, besleme hatti, dis ortam veya yedek sicaklik |
| PCF8574/PCF8575 role/input expander | `PB8`, `PB9` | I2C1 | Paylasimli | Pano ici dusuk hizli iklim cikislari/inputlari |
| Modbus/RS485 iklim modulu | `PA9`, `PA10`, `PB11` | USART1 + DE | Paylasimli | Uzun kablo/dagitik sensor-role modulleri |
| Ruzgar hiz/yon sensoru | Gateway USB-RS485 veya `PA9`, `PA10`, `PB11` | Modbus RTU | Onerilen | Dis ortam ultrasonik sensor; gateway uzerinden okumak tercih edilir |
| Debi sensoru | `PB13` | GPIO/EXTI veya timer capture | Ayrilacak | Pulse sayimi icin uygun |
| Dusuk su seviyesi | `PB14` | GPIO input | Ayrilacak | `NC` fail-safe tavsiye edilir |
| Drenaj sensoru | `PB15` | GPIO input | Opsiyonel | 2. dijital input olarak kullanilabilir |
| Hat basinc sensoru | `PC5` | ADC | Ayrilacak | `0.5-4.5V` ise bolucu/sartlandirma gerekir |
| Toprak nem sensoru | `PC5` veya harici ADC | ADC / dijital | Opsiyonel | Kapasitif tip tercih edilmeli |

Pin secim mantigi:

- `PB13`, `PB14`, `PB15` dokunmatik, UART, vana ve EEPROM hatlariyla cakismadan iki veya uc saha dijital girisi ayirmayi saglar.
- `PC5`, mevcut analog hatlardan bagimsiz ek bir analog kanal olarak basinç veya nem olcumu icin uygundur.
- I2C sensorler icin yeni bus acmak yerine mevcut `I2C1` hatti kullanilabilir.
- SCD41 ve PCF genisleticiler I2C uzerinde adres cakismasi olmadan paylasilabilir; uzun sera kablosunda I2C yerine Modbus/RS485 tercih edilmelidir.
- DS18B20 hattinda birden fazla sensor kullanilacaksa her sensorun ROM ID'si gateway/STM32 konfigurasyonunda tutulmalidir.
- Modbus/RS485, USART1 debug hattiyla ayni pinleri kullanirsa urun modunda debug/iklim bus rolu net ayrilmalidir.
- Ruzgar sensoru uzun kablo ve dis ortam ekipmani oldugu icin ilk prototipte Banana Pi/gateway uzerinde ayri USB-RS485 adapter ile okunmalidir.

Donanim notlari:

- Tum saha dijital girislerine `TVS`, `RC filtre` ve `optik izolasyon` veya en azindan `seri direnc + pull-up/pull-down` dusunulmelidir.
- Debi sensoru uzun kabloyla gelecekse `Schmitt trigger` veya opto kat tercih edilmelidir.
- Basinç sensoru 5V beslemeli ise cikis 3.3V ADC uyumlu hale getirilmelidir.

---

## 5. DMA Kanal Ataması

| Kanal | Stream | Fonksiyon | Yön |
|---|---|---|-----|
| DMA2 Stream0 | 0 | ADC1 | Peripheral→Memory |
| DMA2 Stream3 | 3 | SPI1 TX | Memory→Peripheral |
| DMA2 Stream4 | 4 | SPI1 RX | Peripheral→Memory |

Not:

- Isik sensuru I2C uzerinden calisacagi icin ek DMA zorunlu degildir.
- Basinç veya analog nem sensuru eklenirse `ADC DMA buffer` boyutu mevcut `2` kanaldan daha yukari tasinmalidir.

---

## 6. Interrupt Öncelikleri (NVIC)

| Interrupt | Öncelik | Grup | Açıklama |
|---|---|---|---|
| EXTI15_10_IRQn | 0 | 0 | Touch IRQ |
| ADC_IRQn | 1 | 1 | ADC Complete |
| TIM3_IRQn | 2 | 2 | Sistem Timer |
| USART1_IRQn | 3 | 3 | Debug RX |
| I2C1_EV_IRQn | 4 | 3 | EEPROM |

---

## 7. Güç Tüketimi Özeti

| Bileşen | Akım (ortalama) | Gerilim |
|---|---|---|
| STM32F407VET6 | 80 mA @ 168MHz | 3.3V |
| TFT LCD | 100 mA | 3.3V |
| Backlight | 50 mA | 3.3V |
| pH Sensörü | 5 mA | 3.3V |
| EC Sensörü | 5 mA | 3.3V |
| Vanalar (aktif) | 400 mA × 8 | 12V |
| **TOPLAM (MCU+Display)** | **~240 mA** | **3.3V** |
| **TOPLAM (tüm sistem)** | **~3.5 A** | **12V** |

---

## 8. Pin Değişiklikleri (Revizyon Geçmişi)

| Revizyon | Tarih | Açıklama |
|---|---|---|
| 0.1 | 2024-03-15 | İlk taslak |

---

**Sonraki Adım:** Donanım bağlantı şeması oluşturulacak (03_Donanim_Semasi.md)

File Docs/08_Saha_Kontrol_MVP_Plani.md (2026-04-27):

# Saha Kontrol MVP Plani

Bu dokuman, mobil arayuzden once cihazin saha tarafini guvenilir bir kontrolcu haline getirmek icin izlenecek teknik kapsami tanimlar. Odak noktasi, parsel vanalari ve dozaj vanalarinin emniyetli, test edilebilir ve genisleyebilir sekilde yonetilmesidir.

Not: Cihaz mimarisi tek zone degil, `8 parsel` uzerinden calisan `multi-zone` bir kontrolcudur. Bu nedenle orta vadede scheduler yalnizca saat tabanli degil, `parsel bazli dinamik ihtiyac profili` tasiyacak sekilde evrilmelidir.
Not 2: Bu kontrol cekirdegi, dusuk maliyetli `Core` urun ve sensorce zengin `Insight` urun icin ortak kalmalidir. Fark, scheduler iskeletinde degil; etkin ozelliklerde ve sensor kaynaklarinda olmalidir.

## 1. Hedef

Ilk urun surumunde cihaz su uc soruya sahada net cevap vermelidir:

- Hangi parsel vanasi aktif?
- Hangi dozaj vanasi ne oranda suruluyor?
- Hata oldugunda sistem kendini guvenli duruma alabiliyor mu?

Mobil uygulama, bulut ve ileri seviye recete ekranlari bu asamadan sonra gelecektir. Bu fazda ana hedef, kart ustunde calisan cekirdek kontrol yazilimini saglamlastirmaktir.

## 2. MVP Kapsami

MVP once `Core` segmentini sahaya cikaracak kadar yalın olmali, ancak `Insight` segmentine cikisi kapatmamalidir.

### Dahil

- 8 parsel vanasinin tek tek ac/kapa kontrolu
- 5 dozaj vanasinin ayri ayri kontrolu
- Dozaj vanalari icin PWM, duty ve ramp yonetimi
- Parsel bazli sure, bekleme ve sira mantigi
- Manuel baslat/durdur/duraklat/devam ettir akisi
- pH ve EC bazli temel dozaj tetikleme mantigi
- Hata algilama, alarm uretme ve guvenli kapanis
- Enerji kesintisi sonrasi guvenli yeniden baslama davranisi
- EEPROM uzerinden temel parametre kaliciligi

### Dahil Degil

- Mobil uygulama ve kablosuz haberlesme
- Gelismis recete editoru
- Coklu kullanici ve yetkilendirme
- Bulut loglama ve uzaktan izleme
- Uretim dashboardu ve gorsel raporlama

## 3. Basari Kriterleri

- Sistem acilista tum cikislari kapali ve guvenli durumda baslatir.
- Her parsel vanasi tek komutla dogru fiziksel cikisa yansir.
- Her dozaj vanasi duty/frekans parametreleri ile tutarli surulur.
- Yasakli kombinasyonlar yazilim tarafinda engellenir.
- Bir program en az 1 tam parsel dongusunu hatasiz tamamlar.
- Sensor veya vana kaynakli kritik hata durumunda tum cikislar kapanir.
- Yeniden baslatma sonrasi sistem kontrolsuz sekilde vana acmaz.

## 4. Fonksiyonel MVP Modulleri

### 4.1 Valve Layer

Bu katman donanim detayini saklar. Ust katmanlar PCF8574, GPIO veya pin bilgisi bilmez.

Temel sorumluluklar:

- `open(valve_id)`
- `close(valve_id)`
- `close_all()`
- `set_dosing_duty(valve_id, duty_percent)`
- `configure_dosing_channel(valve_id, freq, min_duty, max_duty, ramp_step)`
- `get_state(valve_id)`
- `get_fault(valve_id)`

MVP kurallari:

- Parsel vanalari ile dozaj vanalari tek ID uzayinda kalabilir.
- Dozaj tarafinda `0%` her zaman kapali kabul edilir.
- Duty degisimi ani degil, ramp ile uygulanir.
- `EmergencyStop` her katmanda `close_all()` ile sonuclanir.

### 4.2 Parcel Scheduler

Bu katman siralamayi ve zamanlamayi yonetir.

Temel sorumluluklar:

- Aktif parsel listesini olusturmak
- Mevcut parseli baslatmak
- Sure bitince kapatmak
- Bekleme suresi varsa uygulamak
- Sonraki parsele gecmek
- Program tamamlaninca sistemi `IDLE` durumuna almak

Orta vade genisleme hedefi:

- Statik saat yerine `trigger_mode` tabanli calisma
- `pre-flush`, `dosing`, `post-flush` fazlarini tek akis icinde yonetmek
- Sureye ek olarak hedef hacimle bitis kriteri desteklemek
- LDR veya astronomik saat kaynakli `light bucket` tetikleme eklemek

### 4.3 Dosing Controller

Bu katman pH ve EC icin dozaj adimlarini yonetir.

Temel sorumluluklar:

- Sensor olcumunden hedefe gore doz ihtiyacini hesaplamak
- Uygun dozaj vanasini secmek
- Dozaj suresini, duty degerini ve tepki kazancini belirlemek
- Karistirma ve sensorde etkinin gorunme gecikmesini parametrik yonetmek
- Yeniden olcup gerekiyorsa ikinci duzeltme turunu baslatmak
- Parsel gecislerinde recete degisimi yapmak

MVP kural seti:

- pH ve EC dozaji ayni anda baslamaz.
- Ayni anda birden fazla dozaj vanasi acilsa bile toplam duty limiti yazilim tarafinda sinirlanir.
- Maksimum tek doz suresi asilirsa hata uretilir.
- Sensor geri besleme gecikmesi pH ve EC icin ayri `feedback_delay_ms` parametresiyle ayarlanir.
- Agresif veya yumusak duzeltme `response_gain_percent` ile sahaya gore kalibre edilir.
- pH ve EC duty karari fuzzy rule table ile verilir; hata buyuklugu ve onceki olcume gore hata trendi birlikte kullanilir.
- EC hedefe yaklasirken daha muhafazakar duty carpani kullanilir, cunku EC overshoot ancak seyreltme veya temiz suyla geri alinabilir.
- `Settings > Params` ekranindan `FUZZY` ve eski `LINEAR` duty mantigi arasinda gecis yapilabilir.
- Bu ileri dozaj parametreleri cihazdaki `Settings > Params` ekranindan degistirilir ve EEPROM sistem kaydinda saklanir.
- Ardisik basarisiz doz denemeleri fault sayacina islenir.

### 4.4 Fault Manager

Bu katman hata kodlarini toplar, alarm metni uretir ve guvenli tepkiyi merkezilestirir.

Temel sorumluluklar:

- Sensor timeout
- Sensor out-of-range
- Vana cevap vermiyor suphe durumu
- Doz asimi
- Su seviyesi dusuk
- Asiri akim veya surucu hatasi
- EEPROM/CRC uyumsuzlugu

Cikislar:

- Makine dostu `error_code`
- Kullaniciya uygun kisa alarm metni
- `warning`, `fault`, `latch_fault` seviye ayrimi

## 5. Durum Makinesi Taslagi

Bu fazda iki seviyeli durum makinesi onerilir: ustte calisma akisi, altta dozaj alt akisi.

### 5.1 Ust Durum Makinesi

`BOOT`

- Donanim ve parametreler yuklenir
- Tum cikislar kapatilir
- Sistem `SAFE_IDLE` durumuna gecer

`SAFE_IDLE`

- Calisma yok
- Manuel komut veya program baslatma beklenir

`PRECHECK`

- Sensor gecerliligi
- Su seviyesi
- Aktif fault var mi
- Program ve parsel listesi gecerli mi

`PARCEL_START`

- Secilen parsel vanasi acilir
- `PRE_FLUSH` alt fazi baslar

`PARCEL_ACTIVE`

- `PRE_FLUSH` tamamlanir, ardindan `DOSING` fazina gecilir
- Parsel suresi veya hedef hacim takibi devam eder
- Gerekirse periyodik dozaj kontrol penceresi acilir
- Durdur veya fault gelirse cikis yapilir

`POST_FLUSH`

- Dozaj vanalari kapanir
- Hat temizligi icin yalniz su akisi devam eder
- Tamamlaninca `PARCEL_WAIT` veya `NEXT_PARCEL`

`DOSE_WINDOW`

- pH/EC hedef disinda ise dozaj alt makinesi calisir
- Hedefler uygunsa tekrar `PARCEL_ACTIVE`

`PARCEL_WAIT`

- Iki parsel arasi bekleme uygulanir

`NEXT_PARCEL`

- Siradaki parsele gecilir
- Parsel kalmadiysa `COMPLETE`

`COMPLETE`

- Tum cikislar kapanir
- Ozet istatistik guncellenir
- `SAFE_IDLE`

`FAULT`

- Hata kaydi tutulur
- Tum cikislar kapanir
- Kullanici resetine kadar beklenir veya fault tipine gore temizlenir

`EMERGENCY_STOP`

- Tum cikislar aninda kapanir
- Program iptal edilir
- Elle onay olmadan otomatik devam edilmez

### 5.2 Dozaj Alt Makinesi

`DOSE_IDLE`

- Doz ihtiyaci yok

`DOSE_PRECHECK`

- Hangi kanal aktif olacak belirlenir
- Maksimum duty ve sure limitleri kontrol edilir

`DOSE_PH`

- Asit veya gerekiyorsa baz kanali belirlenen duty ile surulur

`DOSE_EC`

- Receteye gore bir veya birden fazla gubre kanali surulur

`DOSE_MIXING`

- Dozaj kapatilir
- Karistirma icin bekleme uygulanir

`DOSE_SETTLING`

- Akis sakinlesmesi icin beklenir

`DOSE_REMEASURE`

- Sensor tekrar okunur
- Hedefe ulasildiysa `DOSE_IDLE`
- Ulasilmadiysa kontrollu ikinci tura donulur

`DOSE_FAULT`

- Maksimum deneme, sensor hatasi veya zaman asimi durumunda fault uretilir

## 6. Emniyet ve Interlock Kurallari

MVP'de yazilim tarafinda asagidaki interlock kurallari zorunlu olmalidir:

- `close_all()` her zaman tek bir merkez fonksiyon uzerinden calismali
- `Emergency stop` durumunda parsel ve dozaj cikislari ayni anda kapanmali
- Bir parsel aktifken yazilim disi bir ikinci parsel acilamaz
- pH ve EC dozaj fazlari ayni anda baslamaz
- `sensor invalid` iken yeni dozaj fazi baslatilmaz
- `fault latched` durumunda kullanici reseti olmadan yeni program baslatilmaz
- Enerji geri geldiginde sistem otomatik vana acma yapmaz

## 7. Refactor Plani

Mevcut yapida `irrigation_control.c` icinde program akisi, dozaj, runtime backup ve alarm mantigi birlikte buyuyor. Mobil arayuze gecmeden once bu ayristirma yapilmalidir.

### Faz 1: Valve Driver Stabilizasyonu

Hedef dosyalar:

- `stm32/Core/Inc/valves.h`
- `stm32/Core/Src/valves.c`

Isler:

- Parsel ve dozaj cikislarinin komut API'sini sadelestir
- Vanaya ozel fault/status alanlarini netlestir
- Dosing PWM zamanlama kodunu tek sorumlulukta tut
- `close_all`, `emergency_stop`, `set_duty` davranislarini test edilebilir hale getir

Teslim:

- Donanimdan bagimsiz davranis bekleyen net fonksiyon seti

### Faz 2: Dosing Controller Ayrisma

Yeni modul onerisi:

- `stm32/Core/Inc/dosing_controller.h`
- `stm32/Core/Src/dosing_controller.c`

Isler:

- pH ve EC doz karar mantigini `irrigation_control.c` icinden tasimak
- Mixing, settling ve re-measure akislarini bu modulde toplamak
- Tarif oranlarinin uygulanmasini tek yere cekmek

Teslim:

- `start_dose_cycle`
- `update_dose_cycle`
- `stop_dose_cycle`
- `get_dose_status`

### Faz 3: Parcel Scheduler Ayrisma

Yeni modul onerisi:

- `stm32/Core/Inc/parcel_scheduler.h`
- `stm32/Core/Src/parcel_scheduler.c`

Isler:

- Queue ve sira mantigini ayirmak
- Programdaki aktif vana sirasini ayrik bir runtime yapisinda tutmak
- Tek parsel, tum parseller ve program tabanli calismayi ayni scheduler catisinda toplamak

Teslim:

- `build_sequence`
- `start_sequence`
- `update_sequence`
- `advance_sequence`
- `cancel_sequence`

### Faz 4: Fault Manager Ayrisma

Yeni modul onerisi:

- `stm32/Core/Inc/fault_manager.h`
- `stm32/Core/Src/fault_manager.c`

Isler:

- Hata kodlarini, latched/non-latched davranisini ve alarm metinlerini merkezilestirmek
- GUI veya mobil arayuz sonradan degisse bile ayni hata modelini korumak

Teslim:

- `raise_fault`
- `clear_fault`
- `has_active_fault`
- `get_alarm_text`
- `requires_manual_ack`

### Faz 5: Orchestrator Sadelestirme

Hedef dosyalar:

- `stm32/Core/Inc/irrigation_control.h`
- `stm32/Core/Src/irrigation_control.c`

Isler:

- Bu modulun gorevini koordinasyon seviyesine indirmek
- Scheduler, dosing ve fault manager arasindaki ust akisi yonetmek
- EEPROM runtime backup ve durum gecislerini burada koordine etmek

Teslim:

- Daha kucuk, okunabilir ve test senaryosuna uygun bir ana kontrol modulu

## 8. Mevcut Dosya Yapisi Icin Onerilen Sorumluluk Dagilimi

- `valves.*`
  Fiziksel cikis surme, valve state, duty/ramp

- `sensors.*`
  Sensor okuma, filtreleme, validity

- `dosing_controller.*`
  pH/EC doz mantigi ve alt durum makinesi

- `parcel_scheduler.*`
  Parsel sirasi, sure, bekleme, tekrar

- `fault_manager.*`
  Alarm, fault, interlock, manual acknowledge

- `irrigation_control.*`
  Ust koordinasyon ve run lifecycle

- `gui.*`
  Sadece gosterim ve komut girisi

## 9. Donanim Dogrulama Sirasi

Mobil arayuze gecmeden once kart ustunde asagidaki sira ile dogrulama yapilmalidir:

1. Parsel vanalari tek tek dogru cikisa gidiyor mu
2. Dozaj vanalari tek tek dogru duty ile suruluyor mu
3. `close_all` tum kanallari aninda kapatiyor mu
4. Bir tam parsel dongusu zamanlama hatasi olmadan tamamlanabiliyor mu
5. pH ve EC doz akislari GUI'yi kilitlemeden ilerliyor mu
6. Sensor hatasinda fault durumu latched sekilde tutuluyor mu
7. Reset sonrasi cihaz guvenli `SAFE_IDLE` durumunda aciliyor mu

## 10. Kabul Testi Paketi

Bu MVP tamamlandi sayilabilmesi icin en az su testler gecmelidir:

- 8 parsel vanasi icin manuel ac/kapat testi
- 5 dozaj vanasi icin duty testi
- 1 tam program akisi: parsel, bekleme, sonraki parsel
- 1 tam faz akisi: pre-flush, dosing, post-flush
- 1 pH dusurme doz senaryosu
- 1 EC arttirma doz senaryosu
- 1 sensor timeout senaryosu
- 1 emergency stop senaryosu
- 10 yeniden baslatma sonrasi guvenli acilis testi

## 11. Sonraki Adimlar

Bu dokumana gore ilk uygulama sprint'i su sekilde baslatilabilir:

1. `valves` modulu icin net API ve interlock temizligi
2. `irrigation_control` icinden dozaj akislarini ayri modula tasima
3. Queue ve parsel runtime mantigini scheduler modulune ayirma
4. Hata/alarm modelini tek merkezde toplama
5. Kart ustu smoke test ve kabul checklist guncellemesi

Bu paket tamamlandiginda mobil uygulama artik dogrudan donanima degil, saglamlasmis bir kontrol cekirdegine baglanir.

## 12. Segment Uyum Kurali

Refactor sirasinda su kural korunmalidir:

- `Core` surum compile-time veya runtime feature flag ile calisabilmeli
- `Insight` surum ayni state machine'i daha fazla sensorle beslemeli
- `Core` icin gerekli olmayan sensor yoklugunda kontrol akisi bozulmamali
- GUI, ozellik gosterimini aktif urun seviyesine gore sadeleştirebilmeli

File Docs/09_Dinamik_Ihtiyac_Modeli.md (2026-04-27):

# Dinamik Ihtiyac Modeli

Bu dokuman, urunun sulama mantigini "saat kacta basla" anlayisindan "bitki ne zaman ihtiyac duyuyor" anlayisina tasimak icin hedef mimariyi tanimlar.

## 1. Urun Karari

Bu proje tek vana degil, zaten `8 parsel` cikisina sahip bir `multi-zone` kontrolcu olarak konumlanmis durumdadir. Bu nedenle sulama mantigi yalnizca global bir zamanlayici olarak degil, `parsel bazli recete` ve `parsel bazli tetikleme` dusuncesiyle ele alinmalidir.

Temel urun karari:

- Basit mod kullaniciyi saat ve dakika detayina bogmaz.
- Pro mod, isik ve sensor verisinden faydalanarak sulamayi erteler veya siklastirir.
- `Insight` modu, ek sensor zorunlulugu olmadan konum bazli hava/tarimsal internet verisini sanal sensor gibi kullanir.
- Kamera modulleri bitki ve zemin gozlemini karar gerekcesine ekler.
- Tum modlar ayni saha kontrol cekirdegi icinde calisir.
- Sulama akisi her zaman ayni fiziksel fazlara bolunur: `pre-flush`, `dosing`, `post-flush`.
- Bu mimari iki urun seviyesine haritalanir: `Core` ve `Insight`.

## 2. Tetikleme Seviyeleri

### 2.1 Seviye 1: Periyot Tabanli Basit Mod

Kullanici dogrudan `08:00` girmek yerine bir baslangic ankrajina ve tekrar mantigina karar verir.

Onerilen kullanici modeli:

- `Gun dogumundan 2 saat sonra basla`
- `Her 2 saatte bir tekrar et`
- `Gunde en fazla 5 kez sula`

Teknik notlar:

- Mevsim gecislerinde manuel saat kaydirmayi azaltmak icin LDR veya astronomik saat destegi kullanilir.
- Astronomik saat ilk fazda yazilimsal olarak eklenebilir; ek donanim zorunlu degildir.
- Basit mod, firmware icinde yine `dinamik tetikleme` olarak tutulur; yalnizca arayuz sadeleştirilir.

Ilk firmware modeli:

| Alan | Tip | Basit moddaki anlami | Ilk varsayilan |
|---|-----|---|---|
| `trigger_mode` | enum | `FIXED_WINDOW`, `PERIODIC`, `SUNRISE_PERIODIC` | `FIXED_WINDOW` |
| `start_hhmm` | HHMM | `PERIODIC` icin sabit saat ankraji | `0600` |
| `anchor_offset_min` | int16 | Ankrajdan once/sonra dakika kaymasi | `0` |
| `period_min` | uint16 | Iki tetikleme arasi minimum sure | `120` |
| `max_events_per_day` | uint8 | Bir gunde en fazla kac tetikleme | `1` |
| `days_mask` | bitmask | Haftanin hangi gunleri aktif | `0x7F` |
| `last_run_day` / `last_run_minute` | runtime kaydi | Ayni slotun tekrar calismasini engeller | otomatik |

Karar kurali:

1. Program pasifse veya gun maskesi uymuyorsa tetiklenmez.
2. `FIXED_WINDOW` eski davranisi korur: pencere icinde gunde bir kez calisir.
3. `PERIODIC`, `start_hhmm + anchor_offset_min` dakikasini gunluk ankraj kabul eder.
4. `SUNRISE_PERIODIC`, ilk fazda yazilimsal `06:00 + anchor_offset_min` ankrajini kullanir.
5. `period_min` doldukca yeni slot acilir; `max_events_per_day` asildiginda o gun biter.
6. Program basariyla calismaya girince `last_run_day` ve `last_run_minute` yazilir.

Basit mod UI karsiligi:

- Ankraj: `Sabit Saat` veya `Gun Dogumu`
- Kaydirma: `-120..+720 dk`
- Tekrar: `30..1440 dk`
- Gunluk limit: `1..24`

Not: `SUNRISE_PERIODIC` icin `06:00` yalnizca ilk faz placeholder'idir. Astronomik hesap veya isik sensoru eklendiginde ayni alanlar korunur; sadece ankraj kaynagi daha dogru hale gelir.

### 2.2 Seviye 2: Hacim Tabanli Sulama

Sulama sonlandirma kriteri sure degil, hedef hacim olmalidir.

Onerilen model:

- Her parsel icin `target_volume_l` tutulur.
- Debi sensoru yoksa, vana acildiginda bir kere `nominal_flow_lpm` kalibre edilir.
- Runtime sirasinda yazilimsal litre sayaci hesaplanir.
- Debimetre eklenirse ayni API fiziksel olcumle beslenir.

Bu yaklasim su faydalari saglar:

- Hat basinci degisse de sulama dozu daha tutarli kalir.
- Gubreleme recetesi zaman kaymasindan daha az etkilenir.
- Post-flush suresi ayrik tutulabildigi icin damlatici temizligi korunur.

### 2.3 Seviye 3: Internet Context / ET0 / Isik Birikimi

Gercek inovasyon katmani, ek sensor zorunlulugu olmadan konum bazli hava ve tarimsal veriyi bir "sanal iklim sensori" gibi kullanarak sulama karari vermektir. Fiziksel isik sensori daha sonra ayni modele daha dogru lokal veri saglar.

Onerilen model:

- Girdi kaynagi: hava tahmini, gerceklesen hava, global radyasyon, ET0, yagis, sicaklik, nem, ruzgar
- Opsiyonel lokal sensor: LDR, PAR/isik sensoru, debi, basinç, drenaj veya toprak nemi
- Runtime birikim alani: `light_integral_bucket`
- Context alanlari: `weather_et0_x100`, `radiation_wh_m2`, `rain_probability_pct`, `context_age_min`
- Esik parametresi: `bucket_threshold`
- Kullanici parametresi: `sensitivity`

Karar mantigi:

1. Gateway konum bazli hava/tarimsal veriyi periyodik ceker.
2. Radyasyon, ET0, sicaklik, nem ve yagis riski normalize edilir.
3. Urun tipi ve donemi ile parsel hassasiyeti uygulanir.
4. Sistem `koru`, `artir`, `azalt` veya `ertele` tavsiyesi uretir.
5. Operator onayi veya guvenli feature flag olmadan kritik program degismez.
6. Sulama yapildiginda bucket veya gunluk ihtiyac bakiyesi guncellenir.

Beklenen davranis:

- Bulutlu havada sulama kendiliginden seyreklesir.
- Gunesli havada daha sik sulama olur.
- Yagis riski varsa acik alan programi ertelenebilir veya azaltma onerisi alir.
- Sera modunda yagis dogrudan azaltma sebebi olmaz; radyasyon, sicaklik ve nem daha yuksek agirlik alir.
- Kullanici "daha sık" yerine yalnizca hassasiyet ayariyla sistemi yonetir.

### 2.4 Seviye 4: Kamera Destekli Gozlem

Kamera, ilk fazda dogrudan kontrol emri uretmez. Hava ve urun donemi tavsiyesinin sahadaki goruntuyle tutarliligini artirir.

Ilk kamera siniflari:

- kamera sagligi ve goruntu var/yok
- bitki kaplama veya yesillik orani
- zemin islak/kuru gorunum sinifi
- solgunluk/stres icin basit risk skoru
- belirgin akinti veya damlatma anomalisi uyarisi

Kamera sonucunun etkisi:

- hava verisi "azalt" derken zemin cok kuru gorunuyorsa tavsiye "koru"ya cekilebilir
- hava verisi "artir" derken zemin islak gorunuyorsa operator uyarisi uretilir
- kamera kalitesi dusukse karar motoru bunu guven skoru dususu olarak isaretler

## 3. Ortak Sulama Fazlari

Hangi tetikleme modeli secilirse secilsin, fiziksel sulama akisi asagidaki fazlarla calismalidir:

### 3.1 Pre-Flush

- Bekleyen veya isinmis suyu tahliye eder.
- Tipik sure: `60-120 sn`
- Dozaj vanalari bu fazda kapali kalir.

### 3.2 Dosing

- Ana sulama fazidir.
- Sirai PWM vanalari bu fazda aktif olur.
- pH ve EC hedefleri bu fazda kontrol edilir.
- Hedef bitis kriteri sure, hacim veya dinamik ihtiyac motorundan gelebilir.

### 3.3 Post-Flush

- Sulama bitmeden `2-3 dk` once dozaj kapanir.
- Hat ve damlaticilarda gubre kalmasi engellenir.
- Tikama ve yosun riskini azaltir.

## 4. Donanim Onerileri

Minimalist urun icin zorunlu ve opsiyonel genisleme alanlari:

### Zorunlu

- `2 adet dijital input` ayrilmali
- `RTC/astronomik saat` destegi olmali
- `8 parsel` yapisi korunmali

### Onerilen

- `LDR` veya daha lineer bir isik sensoru
- `Drenaj sensori` girisi
- `Toprak nem sensori` girisi
- Ana hat debisi icin kalibrasyon parametresi

Tercih edilen sensor seti:

- Isik icin `BH1750` veya `VEML7700`
- Hacim icin pulse cikisli debi sensoru
- Emniyet icin dusuk su seviyesi switch'i
- Saha tanisi icin `0-3.3V` uyumlu basinç sensoru

Dijital input kullanim modeli:

- DI-1: drenaj geri bildirimi veya dusuk basinç / akış teyidi
- DI-2: toprak nemi veya harici kilit girişi

Bu urun icin tavsiye edilen minimum sensor paketi:

- `Isik + debi + dusuk su seviyesi`

Saha guvenilirligi odakli paket:

- `Isik + debi + dusuk su seviyesi + hat basinç`

## 5. Yazilim Veri Modeli

Mevcut veri modeli buyuk olcude statik zaman alanlarina yaslaniyor:

- `start_hhmm`
- `end_hhmm`
- `irrigation_min`
- `wait_min`

Bir sonraki iterasyonda program modeli asagidaki alanlara evrilmelidir:

- `trigger_mode`
- `start_anchor`
- `max_events_per_day`
- `target_volume_l_x10`
- `nominal_flow_lpm_x10`
- `light_bucket_threshold`
- `sensitivity_level`
- `site_profile_id`
- `parcel_profile_id`
- `crop_profile_id`
- `crop_stage_id`
- `context_policy`
- `max_context_adjust_pct`
- `pre_flush_sec`
- `post_flush_sec`
- `sensor_gate_mask`
- `recipe_profile_id`

Boylece ayni parsel icin farkli urun tipleri, urun donemleri, mevsimler ve konum bazli hava kosullarina gore farkli receteler tanimlanabilir.

## 6. Multi-Zone Sonucu

Bu urun icin dogru yon `multi-zone + parsel bazli recete` modelidir.

Bunun pratik anlami:

- Her parsel icin ayri sulama tetikleme profili tutulur.
- Her parsel icin ayri pH/EC hedefi veya recete profili secilebilir.
- Ortak dozaj altyapisi korunurken karar mantigi parsel bazinda farklilasir.
- Ayni anda yalnizca tek parsel acik kalir; recete degisimi parceller arasi geciste uygulanir.

## 7. Onerilen Urun Modlari

### Basit Mod

- Ankraj: gun dogumu / gun batimi / sabit saat
- Tekrar araligi
- Gunluk maksimum tekrar
- Sulama miktari: dakika yerine litre veya "standart tur"

### Pro Mod

- Isik birikimi tabanli tetikleme
- Internet hava/tarimsal context ile ET0/radyasyon/yagis tabanli tavsiye
- Urun donemi ve parsel profiline gore program overlay'i
- Kamera gozlemi ile tavsiye guven skoru
- Sensor gate kullanimi
- Parsel bazli recete
- Pre-flush ve post-flush ince ayari

## 8. Urun Segmentlerine Haritalama

### `Core` Surum

- Hedef: kucuk ciftci, az kurulum, dusuk maliyet
- Arayuz: cok daha sade
- Tetikleme: periyot, sabit ankraj, gunluk tekrar siniri
- Bitiş: sure veya yazilimsal litre tahmini
- Sensorler: en az `RTC + dusuk su seviyesi`, tercihen debi

Bu seviyede hedef "en akilli cihaz" olmak degil, "en az ayarla guvenilir verim" sunmaktir.

### `Insight` Surum

- Hedef: isletme mantigiyla calisan profesyonel tarim kuruluslari
- Arayuz: daha fazla tanilama ve recete esnekligi
- Tetikleme: internet context, urun donemi, isik birikimi, hacim, sensor gate
- Bitiş: gercek litre, basinç dogrulama, drenaj geri bildirimi
- Sensorler: ek sensor zorunlu degil; `isik + debi + dusuk su seviyesi + hat basinç` saha kalitesini artirir, kamera opsiyonel/fark yaratan paket olur

Bu seviyede hedef, yalniz sulama kontrolu degil; operasyonel kararlari destekleyen veri katmani da sunmaktir.

## 9. Firmware Yol Haritasi

Asagidaki sirayla ilerlemek riskleri dusurur:

1. `pre-flush`, `dosing`, `post-flush` fazlarini mevcut scheduler akisina ekle
2. Program modeline `trigger_mode` ve flush alanlarini ekle
3. Sure tabanli bitis kriterine ek olarak `hedef hacim` secenegi ekle
4. Gateway tarafinda internet context modelini ve provider adapter'larini ekle
5. LDR/astronomik saat katmanini `dynamic trigger engine` olarak ayir
6. Dijital inputlardan biriyle `sensor gate` ve inhibit mantigini ekle
7. GUI'de `Basit Mod`, `Pro Mod` ve `Insight Tavsiye` ayrimini sun

Ek segmentleme adimi:

8. `Core` ve `Insight` ozellik setlerini feature flag ile ayir
9. Program modelinde sensor bagimliligini opsiyonel hale getir
10. Kamera gozlemlerini tavsiye motoruna bagla

## 10. Tasarim Ilkesi

Kullanici arayuzunde detay azaltilmali, firmware tarafinda ise karar sistemi zenginlestirilmelidir. Urun degeri, kullanicinin daha fazla saat girmesinde degil, daha az parametreyle daha dogru sulama yapabilmesinde ortaya cikar.

Internet context ve kamera plani icin:

- [Docs/19_Internet_Tarimsal_Veriler_ve_Kamera_Plani.md](Docs/19_Internet_Tarimsal_Veriler_ve_Kamera_Plani.md)

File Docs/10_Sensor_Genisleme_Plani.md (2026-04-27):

# Sensor Genisleme Plani

Bu dokuman, urunun "dinamik ihtiyac" hedefine uygun ek sensorleri; donanim, pin atamasi ve firmware etkisiyle birlikte tanimlar.

Bu plan varsayilan olarak `Insight` urun seviyesini hedefler. `Core` seviyede bu sensorlerin bir kismi opsiyonel veya yok kabul edilmelidir.

2026-04-27 karar guncellemesi:

- `Insight` ek fiziksel sensor zorunlulugu olmadan, once konum bazli internet hava/tarimsal verisini sanal sensor gibi kullanmalidir.
- Fiziksel sensorler ve kamera modulleri karar kalitesini artiran ek kanit kaynaklari olarak fazlandirilmalidir.
- Sera iklimlendirme icin SCD41 ana ic ortam sensoru, DS18B20/1-Wire yardimci sicaklik hattidir.
- Ruzgar hiz/yon icin tercih RS485/Modbus ultrasonik ruzgar sensorudur.
- Detayli context plani: [Docs/19_Internet_Tarimsal_Veriler_ve_Kamera_Plani.md](Docs/19_Internet_Tarimsal_Veriler_ve_Kamera_Plani.md)
- Sera iklim plani: [Docs/20_Sera_Iklimlendirme_Plani.md](Docs/20_Sera_Iklimlendirme_Plani.md)

## 1. Tasarim Karari

Ilk yazilim genisleme paketi, ek donanim takmadan su sanal sensor/context alanlarini kullanmalidir:

1. Konum bazli hava tahmini ve gerceklesen hava
2. Radyasyon / guneslenme / ET0
3. Yagis riski ve don/uyari bilgisi
4. Urun tipi, dikim tarihi ve donem bilgisi
5. Sera ic iklimi icin SCD41 CO2/nem/sicaklik olcumu

Fiziksel genisleme paketinde su dort sensor en yuksek degeri uretir:

1. Isik sensoru
2. Debi sensoru
3. Dusuk su seviyesi sensoru
4. Hat basinc sensoru

Opsiyonel katman:

- Kamera modulu
- SCD41 veya Modbus CO2/nem/sicaklik sensoru
- DS18B20/1-Wire sicaklik problari
- RS485/Modbus ultrasonik ruzgar hiz/yon sensoru
- Drenaj sensori
- Toprak nem sensori

## 2. Onceliklendirme

| Sensor | Oncelik | Neden |
|---|---|---|
| Internet hava/tarimsal context | P0 | Ek sensor olmadan ET0, radyasyon, yagis ve sicaklikla karar kalitesini artirir |
| SCD41 CO2/nem/sicaklik | P0 | Sera ic iklimi, VPD ve havalandirma/golgeleme/sisleme kararlari icin ana sensor |
| DS18B20 / 1-Wire sicaklik | P1 | Su deposu, besleme hatti, dis ortam veya yedek sicaklik noktasi |
| Ultrasonik ruzgar hiz/yon | P1 | Havalandirma, perde, sisleme ve firtina emniyeti icin dis ortam girdisi |
| Isik sensoru | P1 | `light bucket` ve mevsimsel kayma duzeltmesi |
| Debi sensoru | P1 | Sulamayi sure yerine hacimle bitirmek |
| Dusuk su seviyesi | P1 | Kuru calisma korumasi |
| Hat basinc sensoru | P2 | Akis teyidi, tikali filtre, pompa arizasi ayirimi |
| Kamera modulu | P2 | Bitki/zemin gozlemi ve tavsiye gerekcesi |
| Drenaj sensoru | P3 | Geri bildirim ve inhibit |
| Toprak nem sensoru | P3 | Yardimci karar / alarm |

## 2.1 Segment Bazli Uygulama

| Sensor | `Core` | `Insight` |
|---|---|---|
| Internet hava/tarimsal context | Yok veya premium | Zorunlu |
| SCD41 CO2/nem/sicaklik | Yok veya premium | Zorunlu sera paketi |
| DS18B20 / 1-Wire sicaklik | Opsiyonel | Onerilen |
| Ultrasonik ruzgar hiz/yon | Yok veya premium | Onerilen sera paketi |
| Isik | Opsiyonel | Onerilen |
| Debi | Opsiyonel | Zorunluya yakin |
| Dusuk su seviyesi | Zorunlu | Zorunlu |
| Hat basinc | Yok veya opsiyonel | Onerilen |
| Kamera | Yok | Opsiyonel/fark yaratan paket |
| Drenaj | Yok | Opsiyonel |
| Toprak nem | Opsiyonel | Opsiyonel |

## 3. Onerilen Fiziksel Sensorler

| Islev | Onerilen tip | Arabirim |
|---|---|---|
| Sera ic iklim | `SCD41` | I2C |
| Yardimci sicaklik | `DS18B20` veya turevleri | 1-Wire |
| Ruzgar hiz/yon | `RK120-07` sinifi ultrasonik veya Gill `WindSonic` | RS485/Modbus |
| Isik | `BH1750` veya `VEML7700` | I2C |
| Debi | Hall etkili pulse cikisli debimetre | Dijital pulse |
| Dusuk su seviyesi | Samandira switch veya kuru kontak | Dijital input |
| Hat basinc | Endustriyel `0.5-4.5V` transmitter | Analog |
| Drenaj | Kuru kontak, optik veya iletkenlik tabanli seviye | Dijital input |
| Toprak nem | Kapasitif nem sensoru | Analog veya threshold dijital |

## 4. Onerilen Pin Atamasi

Bu oneriler, mevcut repodaki pin kullanimina gore cakisma en az olacak sekilde secilmistir.

| Sensor | MCU Pin | Arabirim | Firmware rolü |
|---|---|---|---|
| Isik | `PB8/PB9` | I2C1 | `light_bucket`, gun dogumu ankraji, sensor sagligi |
| SCD41 | `PB8/PB9` | I2C1 | CO2, nem, sicaklik, VPD ve iklim sensor sagligi |
| DS18B20 | `PB12` | 1-Wire | su deposu, besleme hatti, dis ortam veya yedek sicaklik |
| Ruzgar hiz/yon | Gateway USB-RS485 veya `PA9/PA10 + PB11` | Modbus RTU | dis ruzgar, firtina, havalandirma/perde emniyeti |
| Debi | `PB13` | EXTI / counter | `delivered_volume_l`, akiş var teyidi |
| Dusuk su seviyesi | `PB14` | Dijital input | `ERR_LOW_WATER_LEVEL`, start inhibit |
| Drenaj | `PB15` | Dijital input | post-irrigation kontrol, yeni tur inhibit |
| Hat basinc | `PC5` | ADC | basinç esigi, filtre/pompa fault ayrimi |
| Toprak nem | `PC5` veya harici ADC | ADC | parcelye ozel inhibit veya advisory |

Varsayim:

- `PB13`, `PB14`, `PB15` custom sulama kartinda saha inputlari icin ayrilabilir.
- `PC5` custom kartta analog genisleme girisi olarak ayrilabilir.
- I2C1 hatti uzerindeki toplam kapasitans saha kablolamasina gore gozden gecirilmelidir.
- PCF8574/PCF8575 ayni I2C bus uzerinden pano ici role/input cogaltma icin kullanilabilir.
- Modbus/RS485 uzun kablo, dagitik sera sensoru veya role modulu icin PCF'e gore daha dogru saha yoludur.
- Ruzgar sensoru dis ortamda olacagi icin I2C/analog yerine RS485/Modbus tercih edilmelidir.

## 5. Sensorlere Gore Firmware Davranisi

### 5.1 Isik Sensoru

Kullanim:

- `light_bucket += lux * delta_t`
- `bucket_threshold` asildiginda sulama turu tetiklenir
- Gun dogumu referansi gerekiyorsa lux esigiyle gunduz baslangici bulunabilir

Ariza davranisi:

- I2C timeout veya sabit deger algilanirsa `warning`
- Basit mod zaman/periyot mantigiyle devam edilebilir

### 5.2 Debi Sensoru

Kullanim:

- Her pulse bir `kalibrasyon_katsayisi` ile litreye cevrilir
- `target_volume_l` dolunca parsel sulamasi biter
- Beklenen basinç varken pulse yoksa fault uretilebilir

Ariza davranisi:

- Pulse yok ama vana acik ve basinç var ise `flow anomaly`
- Debi sensori yoksa yazilimsal sayaç fallback'i kullanilabilir

### 5.3 Dusuk Su Seviyesi

Kullanim:

- Program baslatmadan once interlock
- Calisma sirasinda aktif olursa tum dozaj ve parsel cikislarini kapat

Ariza davranisi:

- `latched fault` tavsiye edilir
- Kullanici onayi olmadan otomatik restart yapilmaz

### 5.4 Hat Basinc Sensoru

Kullanim:

- Vana acikken hatta yeterli basinç geliyor mu kontrol edilir
- Debi ile birlikte kullanilirsa:
  basinç var + debi yok = tikali hat / kapali vana
  basinç yok + debi yok = pompa veya besleme problemi

Ariza davranisi:

- Esik alti uzun surerse `warning` veya `fault`

### 5.5 Drenaj Sensoru

Kullanim:

- Sulama sonrasi drenaj var/yok geri bildirimi
- Asiri drenaj durumunda bir sonraki tur ertelenebilir

### 5.6 Toprak Nem Sensoru

Kullanim:

- Ana karar motoru yerine `gate` olarak tavsiye edilir
- Ornek: toprak halen islaksa yeni turu ertele

Sinirlama:

- Tek sensorle tum parseli temsil etmek risklidir

## 6. Onerilen Kart Revizyonu

Yeni kartta su konektorler ayrilmalidir:

- `J_I2C_SENS`
- `J_FLOW_IN`
- `J_LEVEL_IN`
- `J_DRAIN_IN`
- `J_PRESS_IN`

Elektriksel gereksinimler:

- Saha dijital girislerinde opto veya endustriyel seviye uyarlama
- Ters polarite ve ESD korumasi
- Analog hatta RC filtre ve TVS
- 5V sensor kullanilacaksa ADC icin bolucu/op-amp uyarlama

## 7. Yazilim Backlog'una Etkisi

Bu sensor paketi eklendiginde asagidaki isler acilmalidir:

1. `sensors.*` icine isik, basinç ve dijital input alt yapisi eklenmesi
2. `irrigation_program_t` icine `target_volume`, `bucket_threshold`, `sensor_gate_mask` alanlarinin eklenmesi
3. `parcel_scheduler` icinde sureye ek olarak hacim bazli bitis kontrolu
4. `fault_manager` icine `low_water`, `flow_anomaly`, `low_pressure` fault kodlari
5. GUI'de `Basit Mod` ve `Pro Mod` icin yeni sensor durum alanlari

## 8. Net Oneri

`Core` icin en dengeli ilk paket:

- RTC
- dusuk su seviyesi switch'i
- opsiyonel debi veya yazilimsal debi kalibrasyonu

`Insight` icin en dengeli ilk saha paketi:

- konum bazli internet hava/tarimsal context
- urun donemi ve parsel profili
- SCD41 ile ic CO2/nem/sicaklik
- DS18B20 ile su deposu veya besleme hatti sicakligi
- RS485/Modbus ultrasonik ruzgar hiz/yon sensoru
- opsiyonel kamera modulu
- `BH1750` veya `VEML7700`
- pulse cikisli debi sensoru
- samandira tip dusuk su seviyesi switch'i
- `0.5-4.5V` cikisli hat basinç sensoru

Boylece urun:

- saat bazli cihaz olmaktan cikar
- litre bazli sulama yapabilir
- gunesli ve bulutlu hava arasinda fark koyabilir
- ek sensor yokken bile internet verisi ve urun donemiyle tavsiye uretebilir
- SCD41 ile VPD, CO2 ve ic iklim durumunu hesaplayabilir
- ruzgar verisiyle havalandirma, perde ve sisleme kararlarini daha emniyetli verir
- PCF veya Modbus role cikislariyla fan, sisleme, golgeleme ve isitma kontrolune evrilebilir
- kamera varsa bitki/zemin gozlemiyle tavsiyeyi guclendirebilir
- saha arizalarini daha dogru ayristirabilir

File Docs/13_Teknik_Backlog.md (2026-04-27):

# Teknik Backlog

Bu dokuman, urun yol haritasini yazilim ve donanim islerine ceviren uygulanabilir backlog listesidir.

Amac:

- `Core` ve `Insight` segmentlerini karistirmadan teknik oncelikleri netlestirmek
- "hemen firmware", "ek donanim ister", "ticari fark yaratir" eksenlerinde karar vermeyi kolaylastirmak
- `TODO.md` icindeki gunluk isleri daha ust seviyeli bir backlog ile hizalamak

## 1. Kullanim Kurali

Bu backlog okunurken su ayrim korunmalidir:

- `TODO.md`: aktif sprint veya yakin vade uygulama listesi
- bu dokuman: orta vade teknik onceliklendirme ve paketleme listesi

## 2. Kategoriler

### A. Hemen Firmware

Ek donanim beklemeden mevcut platformda baslanabilecek isler.

### B. Ek Donanim Ister

Donanim genislemesi, saha baglantisi veya yeni sensor gerektiren isler.

### C. Ticari Fark Yaratir

Musterinin urunu neden sececegini belirginlestiren, satis diline dogrudan yansiyabilecek isler.

## 3. Hemen Firmware

Bu grup once `Core`, sonra `Insight` yolunu acan en hizli islerdir.

| ID | Is | Segment | Oncelik | Gerekce |
|----|----|---|---|---|
| FW-01 | `pre-flush`, `dosing`, `post-flush` akislarini scheduler icinde netlestir | Core + Insight | P0 | Ortak kontrol mantiginin omurgasi |
| FW-02 | `fault manager`, `parcel scheduler`, `dosing controller` sorumluluklarini ayristir | Core + Insight | P0 | Kodun buyumesini guvenli hale getirir |
| FW-03 | Guvenli acilis, guvenli stop, `emergency stop` ve fault latch akislarini tekillestir | Core + Insight | P0 | Saha emniyeti icin kritik |
| FW-04 | EEPROM CRC, versiyonlama ve varsayilan deger fallback akisini tamamla | Core + Insight | P0 | Servis yukunu azaltir |
| FW-05 | TFT ana ekranini gercek durum verisi ve net alarm metinleri ile toparla | Core | P1 | Kullanim kolayligini dogrudan artirir |
| FW-06 | Ilk acilis/kurulum sihirbazi ekle | Core | P1 | Kucuk ciftci segmenti icin en yuksek UX etkisi |
| FW-07 | Basit mod veri modelini tanimla: ankraj + tekrar + gunluk limit | Core | P1 | Saat bagimli karmasayi azaltir |
| FW-08 | Hazir profil mantigi ekle: ornek urun tipleri veya sulama profilleri | Core | P1 | Recete yerine daha kolay kullanim |
| FW-09 | USB masaustu araci ile programlama akislarini sadelelestir ve servis komutlarini artir | Core + Insight | P1 | Sahada hizli devreye alma saglar |
| FW-10 | Program modelini `trigger_mode`, `pre_flush_sec`, `post_flush_sec`, `recipe_profile_id` alanlarina evrilt | Core + Insight | P1 | Gelecek fazlari bloke etmez |
| FW-13 | Kanal bazli kapasite ve dozlama orani modelini ekle: `nominal_capacity_lph`, `1:100`, `1:200`, ozel oran | Core + Insight | P1 | Turkiye pazari icin 50-600 l/sa kanal hedefini firmware'de temsil eder |
| FW-14 | Booster pompa cikisi ve interlock mantigini ekle | Core + Insight | P1 | Dusuk basincli sahalarda Venturi performansini stabil tutar |
| FW-15 | Gateway icin `device_info`, `telemetry_snapshot`, `fault_event`, `runtime_event` paketlerini standartlastir | Insight, premium Core | P0 | Linux edge arayuzun firmware ile temiz konusmasini saglar |
| FW-16 | USB CDC servis protokolunu durum, olay, config ve manuel komut siniflariyla genislet | Insight, premium Core | P0 | Raspbian tarzi gateway MVP'nin ilk baglantisi |
| FW-11 | Alarm gecmisi ve olay gunlugu ekle | Insight | P2 | Tani ve izlenebilirlik getirir |
| FW-12 | Bakim zekasi: kalibrasyon zamani, vana cevrim sayisi, servis hatirlatma | Insight | P2 | Operasyonel deger uretir |

## 4. Ek Donanim Ister

Bu grup `Insight` icin kritik fark yaratir; bazilari `Core` icin opsiyonel premium eklenti olabilir.

| ID | Is | Segment | Oncelik | Gerekce |
|----|----|---|---|---|
| HW-01 | Dusuk su seviyesi girisini saha ile dogrula ve zorunlu emniyet interlock yap | Core + Insight | P0 | En temel emniyet geregi |
| HW-10 | 4+1 Venturi/Z-bypass mekanik mimarisini ticari ilk SKU olarak tasarla | Core + Insight | P0 | Turkiye'de 50-100 dekar segmenti icin en dogru maliyet/kapasite dengesi |
| HW-11 | 110 mm ana hat, statik mikser, flow cell ve servis vanalari icin saha kurulum standardi tanimla | Core + Insight | P0 | Kurulumu standartlastirir ve sensor gecikmesini azaltir |
| HW-02 | Debi sensoru entegrasyonu yap | Insight, opsiyonel Core | P1 | Hacim bazli bitis ve akis tanisi icin temel |
| HW-03 | Hat basinc sensoru girisini ekle | Insight | P1 | Pompa/filtre/hat davranisini anlamayi saglar |
| HW-04 | Isik sensoru (`BH1750` / `VEML7700`) ekle | Insight | P2 | Dinamik ihtiyac tetiklemeyi acar |
| HW-05 | Drenaj geri bildirimi veya inhibit girisi ekle | Insight | P2 | Daha guvenilir sulama dogrulamasi |
| HW-06 | Toprak nemi girisini advisory veya gate roluyle ekle | Insight | P3 | Faydali ama ilk kritik halka degil |
| HW-07 | Debi sensoru icin pulse capture / timer altyapisini guclendir | Insight | P2 | Olcum kalitesini yukselten teknik iyilestirme |
| HW-08 | `STM32` yanina `Raspberry Pi` benzeri Linux edge arayuz/gateway katmani ekle | Insight, premium Core | P0 | Insight'in ana operator ve servis deneyimini tasir |
| HW-09 | Gateway icin `Ethernet` / `Wi-Fi` / opsiyonel `4G` baglanti varyantlarini tanimla | Insight, premium Core | P1 | Saha baglantisini urunlestirir |

## 4.1 Linux Edge / Gateway Isleri

Bu grup, `Insight` surumunu Raspbian/Raspberry Pi OS tarzi arayuz uzerinden urunlestirmek icin yeni omurgadir.

| ID | Is | Segment | Oncelik | Gerekce |
|----|----|---|---|---|
| GW-01 | `gateway/` klasorunde device-agent servis iskeletini baslat | Insight | P0 | STM32 ile Linux edge arasindaki canli kopru |
| GW-02 | USB CDC uzerinden reconnect destekli telemetry okuyucu ekle | Insight | P0 | Ilk saha prototipi icin en hizli baglanti |
| GW-03 | SQLite tabanli event/telemetry store ekle | Insight | P0 | Internet yokken log ve tani kaybolmaz |
| GW-04 | Yerel REST API ve websocket stream ekle | Insight | P0 | Web dashboard ve mobil istemci ayni API'yi kullanir |
| GW-05 | `gateway/ui` altinda canli dashboard prototipi ekle | Insight | P0 | Raspbian arayuz kararinin gorunen urun karsiligi |
| GW-06 | Chromium kiosk modu ve servis autostart paketini tasarla | Insight | P1 | Cihaz ustu ekran deneyimi icin gerekli |
| GW-07 | Rol/izin ve audit log altyapisini ekle | Insight | P1 | Manuel komut ve servis akislari icin emniyet |
| GW-08 | Cloud sync worker icin disk kuyrugu ve MQTT/HTTPS taslagini hazirla | Insight | P2 | Uzak izleme ve filo yonetimine gecis |
| GW-09 | `site_profile` ve `parcel_profile` veri modelini SQLite store'a ekle | Insight | P0 | Konum, urun ve parsel context'i olmadan akilli tavsiye uretilemez |
| GW-10 | Hava/tarimsal veri provider adapter iskeletini ekle | Insight | P0 | Ek sensor zorunlulugu olmadan ET0/radyasyon/yagis context'i saglar |
| GW-11 | `irrigation_advice` ve operator onayli `context_overlay` akisini tasarla | Insight | P1 | Internet verisi programi guvenli sinirlar icinde etkileyebilir |
| GW-12 | Kamera `camera_observation` pipeline taslagini hazirla | Insight | P1 | Kamera modulleri bitki/zemin gozlemini karar gerekcesine baglar |
| GW-13 | `climate-engine` servis veri modelini ekle | Insight sera | P0 | Sera iklimlendirme sulama context'iyle ayni gateway'de yonetilir |
| GW-14 | SCD41 I2C ve DS18B20/1-Wire sensor adapter'larini ekle | Insight sera | P0 | Iklim izleme icin ic sicaklik/nem/CO2 ve yardimci sicaklik verisi gerekir |
| GW-15 | PCF8574/PCF8575 tabanli pano ici role/input genisleme modelini ekle | Insight sera | P1 | Fan, sisleme, golgeleme ve isitma role cikislari icin dusuk pin maliyeti |
| GW-16 | Modbus/RS485 iklim sensor/role modul adresleme modelini tasarla | Insight sera | P1 | Uzun kablo ve dagitik sera panolari icin daha dayanikli yol |
| GW-17 | RS485/Modbus ultrasonik ruzgar hiz/yon sensoru adapter'ini ekle | Insight sera | P1 | Havalandirma, perde, sisleme ve firtina emniyeti icin dis ortam ruzgar verisi gerekir |

## 5. Ticari Fark Yaratan Isler

Bu grup, teknik olarak da degerli ama asil etkisi urunun konumlanmasinda gorulen islerdir.

| ID | Is | Segment | Oncelik | Ticari Etki |
|----|----|---|---|---|
| CV-01 | Kurulum sihirbazi | Core | P1 | "Kolay kurulum" vaadini gercek yapar |
| CV-02 | Hazir profil ve sade arayuz | Core | P1 | Teknik olmayan kullaniciya hitap eder |
| CV-03 | Learned-flow benzeri beklenen akis modeli | Insight | P1 | "Sadece ac-kapa degil, dogrulayan cihaz" algisi yaratir |
| CV-04 | Hacim bazli sulama bitisi | Insight, opsiyonel Core | P1 | Verimlilik dili icin guclu arguman |
| CV-11 | Turkiye pazari icin 50-100 dekar / 10-20 dekar sera hedef paketini netlestir | Core | P1 | Satis mesajini ve mekanik konfigurasyonu somutlastirir |
| CV-05 | Parsel bazli recete secimi | Insight | P1 | Profesyonel kullanimda dogrudan fark yaratir |
| CV-06 | Alarm gecmisi ve servis ekranlari | Insight | P2 | Teknik servis ve isletme yonetimi icin degerli |
| CV-07 | Bakim zekasi | Insight | P2 | Ariza olmadan once mudahale avantaji |
| CV-08 | Uzak izleme ve alarm bildirimi | Insight, premium Core | P2 | Ust segment satis dili icin onemli |
| CV-09 | Linux edge operator ve servis dashboardu | Insight | P0 | Insight'i ayirt eden ana arayuz deneyimi |
| CV-12 | Mobil operator ve servis uygulamasi | Insight, premium Core | P2 | Linux edge API olgunlastiktan sonra saha erisimini genisletir |
| CV-10 | AI destekli alarm ozetleme ve operasyon tavsiyeleri | Insight | P2 | "Akilli operasyon" deger onermesini guclendirir |
| CV-13 | Konum, hava, urun donemi ve kamera destekli sulama asistani | Insight | P1 | Ek sensor zorunlulugu olmadan fark yaratan akilli sulama vaadi |
| CV-14 | Sera iklim asistani ve iklim kontrol paketi | Insight sera | P1 | Sulama + fertigation + iklimlendirme tek platform degerini buyutur |

## 6. Sonraki Sprint Onerisi

Bu repo icin en mantikli kisa-orta vade siralama:

### Sprint 1

- FW-01 `pre-flush`, `dosing`, `post-flush`
- FW-02 moduller arasi sorumluluk ayrimi
- FW-03 guvenli fault ve stop akisi
- FW-04 EEPROM CRC ve fallback

Beklenen sonuc:

- Cekirdek saha davranisi guvenilir hale gelir.

### Sprint 2

- FW-05 sade TFT durum ve alarm ekranlari
- FW-06 kurulum sihirbazi
- FW-07 basit mod veri modeli
- FW-08 hazir profil mantigi
- FW-09 USB servis/programlama iyilestirmesi
- FW-13 kanal kapasitesi ve dozlama orani modelinin veri yapisini tanimla

Beklenen sonuc:

- `Core` segmenti icin ilk ticari kullanim akisi olgunlasir.

### Sprint 3

- HW-10 4+1 Venturi/Z-bypass mekanik hedefini prototiple
- HW-11 110 mm ana hat / flow cell / statik mikser kurulum standardini dokumante et
- FW-15 gateway telemetry/event paketlerini standartlastir
- FW-16 USB CDC servis protokolunu gateway icin genislet
- GW-01 device-agent iskeletini baslat
- GW-02 USB CDC telemetry okuyucu ekle
- GW-03 SQLite event/telemetry store ekle
- GW-09 site/parsel context veri modelini ekle
- GW-13 climate-engine veri modelini ekle

Beklenen sonuc:

- `Insight` Linux edge arayuzunun firmware ile konusabilecegi, konum/parsel context'i ve sera iklim veri modelini tutabilecegi ilk omurga acilir.

### Sprint 4

- GW-04 yerel REST API ve websocket stream
- GW-05 canli dashboard prototipi
- GW-06 kiosk modu ve autostart tasarimi
- HW-02 debi sensoru entegrasyonu tasarimi
- GW-10 hava/tarimsal veri provider adapter iskeleti
- GW-11 operator onayli `irrigation_advice` ve `context_overlay`
- GW-14 SCD41 ve DS18B20 sensor adapter iskeleti
- FW-10 program modelinin evrilmesi
- CV-03 learned-flow mantigi
- CV-04 hacim bazli bitis
- CV-13 konum/hava/urun donemi destekli sulama asistani
- CV-14 sera iklim asistani

Beklenen sonuc:

- `Insight` sahada Linux edge dashboard ile gorunur hale gelir; sensor zenginlestirme, internet context'i ve sera iklim izleme ayni arayuze baglanir.

### Sprint 5

- HW-09 saha baglanti varyantlari
- GW-07 rol/izin ve audit log
- GW-08 cloud sync taslagi
- CV-12 mobil uygulama MVP
- CV-10 AI advisory katmani icin veri modeli
- GW-12 kamera observation pipeline taslagi
- GW-15 PCF tabanli role/input genisleme
- GW-16 Modbus/RS485 iklim modul adresleme
- GW-17 ruzgar hiz/yon sensor adapter'i

Beklenen sonuc:

- Cihaz, internet, kamera, iklim sensorleri, iklim cikislari ve mobil ile baglanan ama saha emniyetini koruyan bir operasyon platformuna donusmeye baslar.

## 7. Teknik Bagimlilik Zinciri

Bazi backlog kalemleri birbirine baglidir:

- `pre-flush/post-flush` olmadan hacim ve recete modeli eksik kalir
- debi sensoru olmadan gercek hacim bitisi eksik kalir
- telemetry/event protokolu sabitlenmeden Linux edge arayuz saglamlasamaz
- gateway store/API olmadan mobil, bulut ve AI katmanlari temiz acilamaz
- site/parsel context olmadan hava, urun donemi ve kamera gozlemleri sulama kararina guvenli baglanamaz
- climate-engine olmadan fan/sisleme/golgeleme/isitma cikislari sulama/fertigation emniyetinden temiz ayrilamaz
- kurulum sihirbazi olmadan `Core` segmentinde kullanim kolayligi iddiasi zayif kalir

Bu nedenle teknik sira su omurga ile korunmalidir:

1. Guvenli kontrol
2. Sade kullanim
3. STM32 telemetry/event protokolu
4. Linux edge gateway ve yerel dashboard
5. Konum, hava/tarimsal veri, urun donemi ve parsel context'i
6. Sera iklim izleme ve climate-engine
7. Akis/dogrulama sensorleri, kamera gozlemleri ve iklim cikislari
8. Recete, tavsiye ve optimizasyon
9. Cloud, mobil ve AI katmani

Baglanti mimarisi icin detay:

- [Docs/14_Baglanti_Mobil_AI_Mimarisi.md](Docs/14_Baglanti_Mobil_AI_Mimarisi.md)

## 8. Repo Icin Net Oncelik

Bugun itibariyla en yuksek getirili ilk 5 is:

1. `FW-15` gateway telemetry/event paketlerini standartlastirmek
2. `FW-16` USB CDC servis protokolunu gateway icin genisletmek
3. `GW-01` device-agent iskeletini baslatmak
4. `GW-09` site/parsel context veri modelini baslatmak
5. `GW-13` climate-engine veri modelini baslatmak

Bu besli, `Core` kontrol cekirdegini korurken `Insight` surumunu Raspbian tarzi arayuz, internet/context ve sera iklim veri katmani uzerinden somut urune cevirir.

Insight edge arayuz detayi:

- [Docs/17_Insight_Raspbian_Arayuz_Plani.md](Docs/17_Insight_Raspbian_Arayuz_Plani.md)
- [Docs/19_Internet_Tarimsal_Veriler_ve_Kamera_Plani.md](Docs/19_Internet_Tarimsal_Veriler_ve_Kamera_Plani.md)
- [Docs/20_Sera_Iklimlendirme_Plani.md](Docs/20_Sera_Iklimlendirme_Plani.md)

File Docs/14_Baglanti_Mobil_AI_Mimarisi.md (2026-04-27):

# Baglanti, Linux Edge Arayuz, Mobil ve AI Katmani Mimarisi

Bu dokuman, cihazi bir sonraki fazda `Raspberry Pi` benzeri bir ara katman ile daha etkin yonetmek, Raspbian/Raspberry Pi OS tarzi yerel arayuz eklemek ve internet/mobil/AI katmanlarini kontrollu sekilde sisteme dahil etmek icin onerilen mimariyi tanimlar.

Temel ilke:

- `STM32` kart, gercek zamanli saha kontrolcusu olarak kalir.
- `Raspberry Pi` benzeri cihaz, `Insight` icin ana Linux edge arayuz ve entegrasyon katmani olarak calisir.
- mobil uygulama ve bulut servisleri, dogrudan role veya dozaj vanasina degil `gateway` uzerinden erisir.
- `AI`, otomatik karar veren kontrol cekirdegi degil; once onerici, tani ve optimizasyon katmani olarak konumlanir.
- konum, hava, tarimsal veri, urun donemi ve kamera gozlemleri gateway uzerinde bir context motorunda birlesir.

Bu ayrim sayesinde internet veya mobil uygulama olmasa bile saha kontrolu calismaya devam eder.

## 1. Neden Ayrik Katman?

Bu urunun ana riski, baglanti ozellikleri eklenirken saha emniyetinin zayiflamasidir. Bu nedenle mimari su sekilde ayrilmalidir:

- `STM32`: vana, sensor, fault ve scheduler kontrolunu yapar
- `Linux Edge/Gateway`: yerel arayuzu calistirir, veri toplar, uzaktan erisim saglar, log senkronize eder
- `Cloud`: cihaz filolari, raporlama, alarm dagitimi ve AI servisleri icin kullanilir
- `Mobile`: Linux edge ve cloud'a baglanan eslikci operator/teknisyen arayuzu olur

Bu model, urunu "tek kutu calisan kontrolcu"dan "bagli operasyon platformu"na tasir.

## 2. Onerilen Katmanlar

### 2.1 Saha Kontrol Katmani - `STM32`

Bu katman mevcut repodaki cekirdektir.

Sorumluluklari:

- parsel ve dozaj vanalarini surmek
- pH/EC olcumlerini almak
- `pre-flush`, `dosing`, `post-flush` akislarini yurutmek
- fault ve `emergency stop` davranisini uygulamak
- temel log ve parametre kaliciligini korumak

Bu katmana eklenmesi onerilen baglanti hazirligi:

- cihaz kimligi (`device_id`)
- firmware surumu
- fault/event kayitlari icin standart olay formati
- anlik durum paketi (`telemetry snapshot`)
- komut kabul katmani: `read-only`, `set parameter`, `manual action`, `ack fault`

### 2.2 Linux Edge Arayuz ve Gateway Katmani - `Raspberry Pi`

Bu katman icin `Raspberry Pi 4`, `Raspberry Pi CM4` veya sahaya gore `Zero 2 W` benzeri bir kart kullanilabilir.

Ana gorevleri:

- `STM32` ile haberlesmek
- cihaz ustunde zengin yerel web arayuzu sunmak
- yerel API saglamak
- veriyi gecici olarak yerelde tamponlamak
- internet varsa buluta senkronize etmek
- internetten konum bazli hava/tarimsal veri cekmek ve ek sensor olmadan karar context'i uretmek
- urun tipi, donem ve parsel profillerini sulama programlariyla iliskilendirmek
- kamera modullerinden gelen gozlemleri tavsiye motoruna kanit olarak baglamak
- mobil istemciye yerel ag veya internet uzerinden servis vermek
- log, alarm, tanilama ve guncelleme akisini merkezilestirmek

Bu katmanin cihaz ustunde sunacagi servisler:

- `Device Agent`: STM32 haberlesme sureci
- `Local API`: REST veya gRPC
- `Local Web UI`: dashboard, commissioning, servis ve recete ekranlari
- `Message Broker`: tercihen `MQTT`
- `Local Store`: SQLite veya benzeri disk tabanli veri kaydi
- `Sync Worker`: bulut senkronizasyonu
- `OTA/Update Worker`: gateway yazilimi ve firmware dagitimi
- `Rule Engine`: internet olmadan calisabilecek basit kural motoru
- `Context Engine`: konum, hava/tarimsal veri, urun donemi, kamera ve cihaz telemetry verisini birlestiren servis

Arayuz tercihi:

- Ilk urunlestirme icin browser tabanli yerel web arayuzu onerilir.
- Cihaz uzerinde ekran varsa Chromium kiosk modunda acilir.
- Telefon/tablet ayni yerel agdayken ayni web arayuzune veya PWA'ya baglanabilir.
- Native mobil uygulama, bu yerel API ve veri modelinden sonra gelmelidir.

### 2.3 Cloud Katmani

Bulut katmani ilk gunden zorunlu olmamali, ama mimari ona acik olmali.

Sorumluluklari:

- cihaz/tesis envanteri
- uzaktan izleme paneli
- alarm dagitimi (`push`, `SMS`, `e-mail`, `WhatsApp` benzeri kanallar)
- tarihsel veri depolama
- raporlama
- AI cikarim servisleri
- kullanici, rol ve yetki yonetimi

### 2.4 Mobil Arayuz Katmani

Mobil uygulama iki farkli persona icin dusunulmelidir, ancak `Insight` v1 icin ana arayuz Linux edge web dashboard olmalidir:

- operator: "su an ne oluyor, alarm var mi, manuel mudahale gerekli mi?"
- teknisyen: "kurulum, servis, kalibrasyon, log, test ve konfig"

Ilk surum icin mobil uygulama su ekranlarla sinirli kalmalidir:

- canli durum ozeti
- aktif parsel / kalan sure
- pH / EC / alarm durumu
- manuel baslat / durdur
- fault detay ve onay
- son olaylar
- program veya profil secimi

Not:

- Mobil uygulama, ilk fazda Linux edge arayuzunun yerel ag/uzak erisim istemcisi gibi tasarlanmalidir.
- Kritik servis ve commissioning akislari once gateway web arayuzunde olgunlastirilmalidir.

## 3. Katmanlar Arasi Iletisim

### 3.1 `STM32 <-> Gateway`

Ilk faz icin en pratik secenek:

- `USB CDC` veya `UART`

Saha dayanikliligi daha yuksek varyant:

- `RS485` fiziksel katman
- ustte `Modbus RTU` veya sade ikili protokol

Onerilen yol:

1. mevcut `USB CDC` protokolunu servis/veri komutlari icin genislet
2. veri modelini tasarla
3. saha urunu icin ayni veri modelini `RS485` tasiyacak sekilde soyutla

Gateway tarafinda gerekli mesaj siniflari:

- `heartbeat`
- `telemetry`
- `fault_event`
- `alarm_event`
- `config_get`
- `config_set`
- `manual_command`
- `program_sync`
- `firmware_info`
- `context_snapshot`
- `irrigation_advice`
- `camera_observation`

### 3.2 Gateway <-> Internet Tarimsal Veri Kaynaklari

Gateway, hava ve tarimsal context icin provider adapter modeli kullanmalidir.

Ilk veri siniflari:

- saatlik/gunluk sicaklik, nem, ruzgar ve yagis tahmini
- global radyasyon veya guneslenme verisi
- ET0 veya evapotranspirasyon icin hesaplanabilir alanlar
- resmi tarimsal uyarilar ve don/yagis riski
- tarihsel hava verisi ve saha performans karsilastirmasi

Kurallar:

- tek bir API'ye kilitlenme olmamali
- internet yoksa son gecerli veri "stale" etiketiyle kullanilmali
- veri kaynagi, zaman damgasi ve veri yasi her tavsiye ile kaydedilmeli
- hava verisi tek basina kritik vana komutu uretmemeli; sadece program overlay veya operator tavsiyesi uretmeli

### 3.3 `Gateway <-> Cloud`

Onerilen protokoller:

- surekli durum ve olay akisi icin `MQTT`
- dosya, rapor ve yonetim API'leri icin `HTTPS`

Onerilen kurallar:

- internet yoksa veri yerelde kuyruklanir
- manuel kritik komutlar bulut onayi beklemeden yerelde islenebilir
- buluttan gelen komutlar rol bazli yetki ve zaman damgasi ile dogrulanir

### 3.4 `Mobile <-> Gateway/Cloud`

Iki mod desteklenmelidir:

- `local-first`: teknisyen yerel agda gateway'e dogrudan baglanir
- `remote`: internet uzerinden bulut araciligiyla baglanir

Bu sayede kurulum ve servis icin saha internetine tam bagimli kalinmaz.

## 4. Onerilen Veri Akisi

Normal isleyis:

1. `STM32` anlik durum ve olaylari gateway'e yollar
2. `Gateway` bu veriyi normalize eder ve tamponlar
3. `Context Engine` konum, hava/tarimsal veri, urun donemi ve kamera gozlemlerini gunceller
4. `Rule/Advice Engine` sulama icin koru/artir/azalt/ertele onerisi veya limitli program overlay'i uretir
5. mobil uygulama yerel API veya bulut uzerinden durumu gorur
6. internet varsa bulut tarihsel veri ve alarm dagitimi yapar
7. `AI` katmani veri uzerinde cikarim yapar ve oneriler uretir

Kritik kontrol kurali:

- vana acma/kapama, acil stop ve fault gibi hareketler her zaman `STM32` tarafinda son karar katmanindan gecmelidir
- `AI` veya mobil arayuzun dogrudan "ham vana surme" yetkisi olmamalidir
- hava, kamera veya urun donemi kaynakli oneriler STM32'nin guvenli program limitlerini asamaz

## 5. AI Katmanini Nereye Koymali?

`AI` ilk asamada "otonom kontrol" icin degil, asagidaki isler icin kullanilmalidir:

- alarm ozetleme
- operatore sade dilde durum aciklama
- anomali tespiti
- sulama/periyot optimizasyonu icin tavsiye
- konum, hava, ET0, urun donemi ve kamera gozlemlerinden sulama tavsiyesi
- bakim tahmini
- kalibrasyon sapmasi fark etme
- tarihsel veri uzerinden "hangi parsel neden daha cok su istiyor?" analizi

Ilk guvenli AI kullanimlari:

- "Son 24 saatte 3 kez dusuk akis alarmi olustu"
- "pH duzeltmesi normalden %20 daha uzun suruyor"
- "3 nolu parselde beklenen akis ile olculen akis arasinda fark var"
- "Bu hafta filtre veya vana kontrolu gerekebilir"

Ilk fazda AI'nin yapmamasi gerekenler:

- dogrudan sulama programi yazmak
- operator politikasi olmadan hava/kamera verisine dayanarak otomatik setpoint degistirmek
- operator onayi olmadan kritik setpoint degistirmek
- fault varken zorla sistemi yeniden baslatmak
- sensor sagligini dogrulamadan otonom dozaj karari vermek

## 6. Mobil Uygulama Kapsami

Minimum uygulanabilir mobil kapsami:

- canli dashboard
- parceller listesi ve anlik durum
- fault/alarm ekrani
- manuel kontrol
- program/profil atama
- temel ayarlar
- cihaz baglanti ve senkron durum gosterimi

Ikinci asama mobil kapsami:

- olay gecmisi
- servis modu
- kalibrasyon sihirbazi
- kullanici/rol bazli yetki
- uzaktan firmware guncelleme takibi

Teknik tercih:

- tek kod tabani icin `Flutter` mantikli bir baslangictir
- ekip web agirlikli ise `React Native` da tercih edilebilir

Bu repo baglaminda karar kriteri:

- hizli prototip ve saha testi icin `Flutter`
- mevcut web stack ile paylasim agir basiyorsa `React Native`

## 7. Guvenlik ve Emniyet Kurallari

Bu fazda en kritik konu siber guvenlikten once operasyonel emniyettir. Ikisi birlikte dusunulmelidir.

Zorunlu kurallar:

- `STM32` internetten dogrudan erisilebilir olmamali
- tum uzaktan komutlar gateway uzerinden gecmeli
- rol bazli yetkilendirme olmadan manuel role komutu acilmamali
- fault durumunda uzaktan yeniden baslatma kisitli olmali
- internet kesintisinde saha kontrolu devam etmeli
- saat senkronu ve olay zaman damgasi tutulmali
- her komut audit log'a yazilmali

## 8. Fazli Uygulama Onerisi

### Faz 2A - Insight Linux Edge MVP

Hedef:

- `STM32` yanina bir `Raspberry Pi` baglayip yerel izleme, dashboard ve servis katmani acmak

Teslimatlar:

- USB/UART ile cihaz baglantisi
- gateway `device agent`
- yerel REST API
- temel web dashboard
- olay ve durum loglama
- fault bildirimleri

Basari olcutu:

- internet olmadan ayni sahada telefondan cihaz durumu gorulebilmeli
- cihaz uzerinde ekran varsa kiosk dashboard acilmali

### Faz 3A - Internet Context ve Kamera Destekli Insight

Hedef:

- ek sensor zorunlulugu olmadan konum, hava, urun donemi ve kamera gozlemleriyle sulama karar kalitesini artirmak

Teslimatlar:

- gateway `site_profile` ve `parcel_profile`
- hava/tarimsal veri provider adapter'lari
- ET0/radyasyon/yagis context store
- urun donemi ve parsel recete iliskisi
- `irrigation_advice` tavsiye modeli
- operator onayli `context_overlay`
- kamera `camera_observation` pipeline taslagi

Basari olcutu:

- sistem internet verisini ve urun donemini kullanarak gerekceli sulama tavsiyesi uretebilmeli; operator onayi olmadan guvenli limit disina cikmamalidir

### Faz 4A - Internet ve Uzak Izleme

Hedef:

- gateway uzerinden uzaktan erisim ve raporlama

Teslimatlar:

- bulut senkronizasyonu
- cihaz kaydi ve kullanici oturumu
- alarm push bildirimi
- cihaz durum gecmisi
- uzaktan profil/program guncelleme

Basari olcutu:

- birden fazla saha cihazi tek panelden izlenebilmeli

### Faz 4B - AI Destekli Operasyon

Hedef:

- cihazin davranisini veri ile aciklayan ve iyilestirme onerileri sunan katmani acmak

Teslimatlar:

- anomaly scoring
- alarm ozetleme
- bakim tahmini
- operator icin dogal dil aciklama
- tavsiye motoru

Basari olcutu:

- AI, operatorun karar kalitesini artirmali; kontrol emniyetini zayiflatmamali

## 9. Bu Repo Icin Somut Teknik Isler

Firmware tarafinda:

- cihaz durum paketi ve olay paketi veri modelini tanimla
- USB servis protokolunu telemetri/fault/log aktarimini kapsayacak sekilde genislet
- `device_id`, `firmware_version`, `hardware_revision` alanlarini netlestir
- fault/event log yapisini standartlastir
- uzaktan yazilabilir ayarlari "guvenli" ve "kritik" diye ayir

Gateway tarafinda:

- `gateway/` altinda ayri servis klasoru ac
- `Python` veya `Go` ile `device agent` baslat
- lokal `MQTT` veya hafif kuyruk yapisi kur
- SQLite tabanli yerel telemetry/event store ekle
- REST API ve websocket olay akisi ekle
- internet kesintisi icin disk tabanli kuyruk ekle
- konum/hava/tarimsal veri icin provider adapter iskeleti ekle
- `site_profile`, `parcel_profile`, `weather_observation`, `camera_observation` ve `irrigation_advice` tablolarini tasarla
- operator onayli program overlay akisini ekle
- `gateway/ui` altinda Linux edge web dashboard baslat

Mobil tarafinda:

- Linux edge web dashboard olgunlastiktan sonra mobil istemci prototipi hazirla
- manuel komut akisini rol bazli tasarla
- alarm detay ve olay gecmisi ekranlarini cikar
- yerel ag ve uzak baglanti modlarini ayir

AI tarafinda:

- ilk veri seti olarak fault, pH, EC, aktif parsel, dozaj sureleri ve akis olaylarini topla
- ikinci veri seti olarak konum, hava, ET0, radyasyon, yagis, urun donemi ve kamera gozlemlerini topla
- AI ciktilarini `advice` ve `alert insight` siniflarina ayir
- AI tavsiyelerini operator onayli akisa bagla

## 10. Net Mimari Karar

Bu urunde en saglikli sonraki adim su olmalidir:

- `STM32` = emniyetli kontrol cekirdegi
- `Raspberry Pi` = Linux edge arayuz, baglanti ve entegrasyon katmani
- `Mobile` = operator/servis eslikci arayuzu
- `Cloud` = filo, rapor ve uzaktan operasyon
- `Context Engine` = konum, hava, urun donemi ve kamera gozlemleri
- `AI` = tani, ozetleme, tavsiye ve optimizasyon

Boylece urun, sahada calisan guvenilir cekirdegini korurken bagli ve akilli bir platforma evrilebilir.

Insight Linux edge arayuz karari icin:

- [Docs/17_Insight_Raspbian_Arayuz_Plani.md](Docs/17_Insight_Raspbian_Arayuz_Plani.md)
- [Docs/19_Internet_Tarimsal_Veriler_ve_Kamera_Plani.md](Docs/19_Internet_Tarimsal_Veriler_ve_Kamera_Plani.md)

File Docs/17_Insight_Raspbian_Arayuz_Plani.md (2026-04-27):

# Insight Raspbian Arayuz Plani

Bu not, `Insight` surumunun Raspbian/Raspberry Pi OS tarzi bir Linux edge arayuzu uzerinden ilerlemesi icin mimari karari ve ilk uygulama planini tanimlar.

## 1. Net Karar

`Insight` surumunde ana operator ve servis deneyimi STM32 uzerindeki 3.2" TFT'ye sigdirilmamalidir. STM32 TFT ekrani yerel acil durum, temel durum ve manuel servis icin kalabilir; zengin dashboard, commissioning, rapor, log ve recete yonetimi Raspberry Pi OS benzeri bir Linux katmaninda verilmelidir.

Bu karar ile urun katmanlari su hale gelir:

- `STM32`: emniyetli saha kontrolcusu
- `Linux Edge`: cihaz ustu arayuz, gateway, log, servis API, yerel veri tabani, konum/hava/urun context motoru, sera iklim motoru
- `Cloud`: filo, rapor, uzaktan erisim ve AI servisleri
- `Mobile`: ilk fazda eslikci istemci; ana mimariyi bloke etmez

## 2. Neden Bu Yon?

- `Insight` kullanicisi daha fazla veri, tani, recete ve servis akisi ister.
- 320x240 TFT zengin dashboard, grafik, log ve commissioning icin dar kalir.
- Linux edge katmani internet olmasa bile sahada yerel web arayuzu sunabilir.
- Ek fiziksel sensor zorunlulugu olmadan konum, hava tahmini, tarimsal veri ve urun donemi bilgisiyle karar kalitesi artirilabilir.
- Kamera modulleri daha sonra ayni gateway uzerinden saha gozlemi ve bitki durum kaniti olarak eklenebilir.
- Sera uygulamalarinda SCD41, DS18B20/1-Wire, PCF tabanli role cikislari ve Modbus/RS485 moduller ayni gateway mimarisine iklim katmani olarak baglanabilir.
- STM32 kontrol emniyeti korunur; gateway veya UI takilsa bile vana/fault kararini STM32 verir.
- Raporlama, AI, update ve mobil entegrasyon sonradan daha temiz eklenir.

## 3. Ilk Insight Mimari Paketi

### Donanim

- Raspberry Pi 4, Compute Module 4 veya endustriyel muadili
- Yerel dokunmatik ekran veya HDMI ekran opsiyonu
- STM32 ile `USB CDC` ilk prototip baglantisi
- Saha urunu icin `UART/RS485` opsiyonu acik tutulur
- Ethernet zorunluya yakin, Wi-Fi opsiyonel, 4G premium opsiyon

### Yazilim

- Raspberry Pi OS benzeri Linux imaji
- `gateway/device-agent`: STM32 protokolunu okuyan servis
- `gateway/api`: yerel REST API ve websocket olay akisi
- `gateway/store`: SQLite tabanli yerel olay, alarm ve telemetry kaydi
- `gateway/context-engine`: konum, hava/tarimsal veri, urun donemi ve kamera gozlemlerini birlestiren servis
- `gateway/climate-engine`: SCD41, DS18B20, VPD, CO2, fan/sisleme/golgeleme/isitma karar katmani
- `gateway/ui`: browser tabanli yerel web arayuzu
- kiosk modu: cihaz ekrani varsa Chromium tam ekran acilir

## 4. UI Kapsami

Insight v1 edge arayuzu su ekranlari icermelidir:

- canli dashboard: aktif parsel, faz, kalan sure, pH, EC, debi, basinç, alarm
- parsel kartlari: durum, son sulama, hedef hacim, recete, beklenen/olculen akis
- alarm ve olay gecmisi
- manuel servis: vana testleri, dozaj kanal testi, pompa/interlock durumu
- commissioning: sensor kalibrasyonu, K-faktor, kanal kapasitesi, dozlama orani
- recete/profil yonetimi
- hava ve tarimsal context: tahmin, ET0, radyasyon, yagis riski, veri yasi
- urun/parsel context: urun tipi, dikim tarihi, donem, hassasiyet ve aktif recete
- kamera gozlemleri: kamera sagligi, parsel goruntusu, bitki/zemin durum siniflari
- tavsiye merkezi: sulama artir/azalt/koru/ertele onerileri ve gerekceleri
- sera iklimi: ic sicaklik, nem, CO2, VPD, dew point, fan/sisleme/golgeleme/isitma durumu
- cihaz sagligi: STM32 baglantisi, firmware surumu, gateway servisleri, disk/ag durumu

STM32 TFT'de kalmasi gerekenler:

- ana durum
- alarm/fault metni
- acil stop veya guvenli durdurma
- temel manuel vana testi
- gateway yokken minimal kullanim

## 5. STM32 <-> Linux Edge Protokol Ihtiyaci

Gateway'in saglikli calismasi icin firmware tarafinda su veri paketleri standartlasmalidir:

- `device_info`: cihaz kimligi, firmware surumu, donanim revizyonu
- `telemetry_snapshot`: state, faz, parsel, pH, EC, debi, basinç, kalan sure
- `fault_event`: fault kodu, severity, timestamp, latch/ack durumu
- `runtime_event`: program basladi, faz degisti, parsel bitti, dozaj basladi/bitti
- `config_get` / `config_set`: guvenli ayar okuma/yazma
- `manual_command`: izinli manuel aksiyonlar
- `program_sync`: program ve recete aktarimi
- `climate_snapshot`: sicaklik, nem, CO2, VPD, iklim zone durumu
- `climate_command`: izinli fan, sisleme, golgeleme, isitma ve havalandirma komutlari

Kritik kural:

- Gateway sadece niyet ve parametre yollar; nihai emniyet kontrolu STM32 tarafinda kalir.
- Internet, AI veya kamera kaynakli kararlar once `advice` olarak uretilir; otomatik program degisikligi yalnizca limitli, audit log'lu ve feature flag arkasinda acilir.
- Iklim cikislari vana/dozaj cikislarindan ayri ID uzayinda tutulur; isitma, sisleme, fan ve perde komutlari ek interlocklardan gecmeden uygulanmaz.

## 6. Ilk Uygulama Sirasi

1. Firmware'de okunabilir `status snapshot` ve `device_info` komutlarini sabitle.
2. `gateway/` klasorunde basit device-agent baslat.
3. USB CDC uzerinden STM32 status okuma ve reconnect davranisini yap.
4. SQLite olay/telemetry kaydi ekle.
5. Yerel REST API ve websocket stream ac.
6. `gateway/ui` ile canli dashboard prototipi yap.
7. `site_profile` ve `parcel_profile` ile konum/urun/parsel veri modelini ekle.
8. Hava/tarimsal veri provider adapter iskeletini ekle ve ET0/radyasyon/yagis verisini logla.
9. Alarm/event gecmisi ve manuel servis ekranlarini ekle.
10. Recete/profil editorunu firmware veri modeli ile bagla.
11. `irrigation_advice` ve operator onayli context overlay akisini tasarla.
12. Kamera gozlem pipeline'ini feature flag arkasinda ekle.
13. SCD41 ve DS18B20 tabanli iklim izleme adapter'larini ekle.
14. `climate-engine` icin VPD/CO2 ve iklim tavsiye modelini ekle.
15. PCF ve Modbus tabanli iklim cikis genisleme planini prototiple.
16. Kiosk modu ve offline-first davranisi test et.

## 7. Basari Kriteri

Insight edge arayuz MVP'si tamamlandi sayilmasi icin:

- internet olmadan cihaz ekranindan veya ayni yerel agdan dashboard acilmali
- STM32 baglantisi kopunca UI bunu net gostermeli ve reconnect yapmali
- son olaylar gateway diskinde kalici tutulmali
- konum, hava/tarimsal context ve urun/parsel profili internet yokken son gecerli veriyle okunabilmeli
- operator vana/fault gibi kritik durumlari UI'da gorebilmeli
- sulama tavsiyeleri veri yasi, kaynak, guven skoru ve gerekce ile gosterilmeli
- iklim tavsiyeleri sensor sagligi, veri yasi ve interlock durumuyla birlikte gosterilmeli
- manuel komutlar rol/izin ve STM32 emniyet kapisindan gecmeli
- UI kapanirsa veya gateway yeniden baslarsa sulama emniyeti bozulmamali

## 8. Plan Degisikligi

Eski varsayim:

- Insight once daha fazla sensor ve mobil/bulut ozelligi ile genisler.

Yeni varsayim:

- Insight once Linux edge arayuz/gateway ile urunlesir; ek sensor zorunlulugu olmadan internet tarimsal verisi, urun donemi ve kamera gozlemi bu katmanin uzerine eklenir.

Bu, `Insight` icin oncelik siralamasini degistirir:

1. STM32 protokol ve telemetry modeli
2. Linux gateway/device-agent
3. Yerel dashboard ve servis arayuzu
4. Konum, hava/tarimsal veri, urun donemi ve recete context modeli
5. Kamera gozlem pipeline'i ve operator onayli tavsiye motoru
6. SCD41/DS18B20 tabanli sera iklim izleme ve `climate-engine`
7. PCF/Modbus tabanli iklim cikis kontrolu
8. Debi/basinç/log/recete zenginlestirmesi
9. Cloud, mobil ve AI

Detayli context plani:

- [Docs/19_Internet_Tarimsal_Veriler_ve_Kamera_Plani.md](Docs/19_Internet_Tarimsal_Veriler_ve_Kamera_Plani.md)
- [Docs/20_Sera_Iklimlendirme_Plani.md](Docs/20_Sera_Iklimlendirme_Plani.md)

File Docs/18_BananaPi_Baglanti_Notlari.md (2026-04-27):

# Banana Pi Baglanti Notlari

Bu dosya, kart ustu testlerde Banana Pi uzerinden ayni baglanti
parametrelerinin tekrar bulunmasi icin tutulur.

## SSH

- Hostname: `serapi`
- IP: `192.168.1.190`
- Kullanici: `sera`
- Parola: `sera`
- SSH komutu: `ssh sera@192.168.1.190`

## STM32 ve DAPLink Portlari

- STM32 USB CDC:
  `/dev/serial/by-id/usb-OktayCit_Irrigation_Controller_Config_Port_207E377C5232-if00`
- Tipik STM32 tty: `/dev/ttyACM1`
- DAPLink CMSIS-DAP:
  `/dev/serial/by-id/usb-ARM_DAPLink_CMSIS-DAP_07000001000000000000000000000000a5a5a5a597969908-if01`
- Tipik DAPLink tty: `/dev/ttyACM0`

## Gateway

- Servis/uygulama dizini: `/home/sera/irrigation-gateway`
- Calisan komut:
  `/usr/bin/python3 /home/sera/irrigation-gateway/app.py --host 0.0.0.0 --port 8080`
- Yerel ag health endpoint: `http://192.168.1.190:8080/health`
- Ping endpoint: `http://192.168.1.190:8080/api/ping`

## Flash / Verify Akisi

Banana Pi uzerinde OpenOCD 0.12.0 kurulu. DAPLink mass-storage kopyalama
`FAIL.TXT` icinde `The transfer timed out` verdigi icin firmware yukleme icin
SWD/OpenOCD yolu kullanilir.

1. Yerelde build al:

   ```bash
   make -j4
   ```

2. Firmware'i Banana Pi'ye kopyala:

   ```bash
   scp stm32/Debug/irrigation.elf stm32/Debug/irrigation.hex sera@192.168.1.190:/home/sera/
   ```

3. Banana Pi uzerinden flash/verify/reset:

   ```bash
   ssh sera@192.168.1.190 \
     'echo sera | sudo -S openocd -f interface/cmsis-dap.cfg -f target/stm32f4x.cfg -c "program /home/sera/irrigation.elf verify reset exit"'
   ```
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

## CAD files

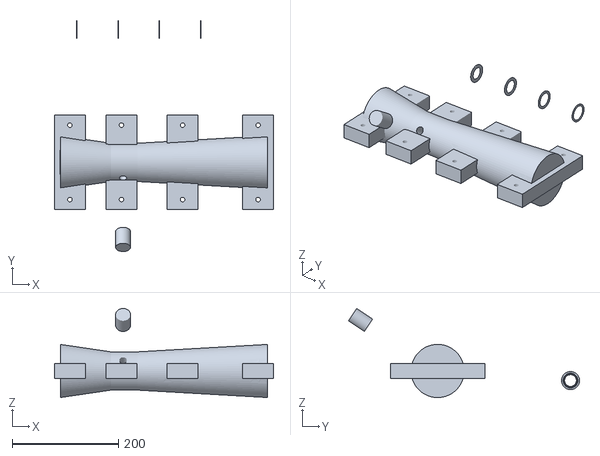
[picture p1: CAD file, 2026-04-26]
mechanical/printable_venturi_stl/Venturi_Printable_Assembly_reference.stl
412.0 x 434.8 x 167.6

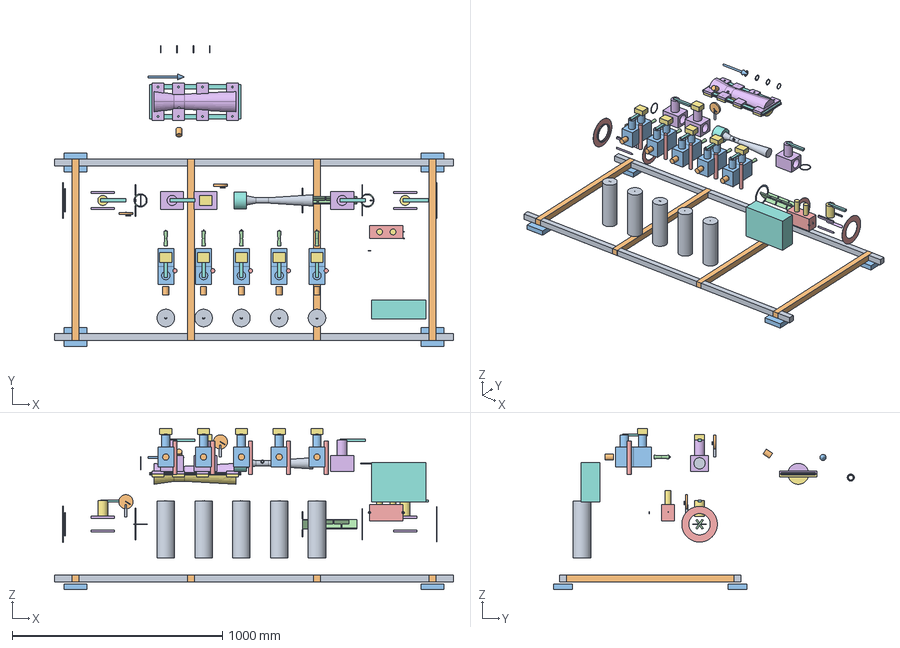
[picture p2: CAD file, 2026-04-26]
mechanical/Irrigation_Venturi_Pulse_40m3h.step
1900.0 x 1432.0 x 769.0 mm
Skid_long_rail_y__650
Skid_long_rail_y_180
Skid_cross_rail_x__850
Skid_cross_rail_x__300
Skid_cross_rail_x_300
Skid_cross_rail_x_850
Skid_foot__850__650
Skid_foot__850_180
Skid_foot_850__650
Skid_foot_850_180
DN110_main_line_40m3h
Inlet_flange_DN110
Outlet_flange_DN110
Main_inlet_isolation_valve
Main_inlet_isolation_valve_handle
Main_outlet_isolation_valve
Main_outlet_isolation_valve_handle
Main_line_pressure_gauge_stem
Main_line_pressure_gauge_dial
Main_line_pressure_gauge_needle
Z_bypass_left_riser_DN50
Z_bypass_upper_run_DN50
Z_bypass_right_riser_DN50
Bypass_inlet_tee_reinforcement
Bypass_return_tee_reinforcement
Bypass_manual_isolation_inlet x 2
Bypass_manual_isolation_inlet_handle x 2
Bypass_master_pulse_valve x 2
Bypass_master_pulse_valve solenoid coil x 2
Bypass_pressure_gauge_stem x 2
Bypass_pressure_gauge_dial x 2
Bypass_pressure_gauge_needle x 2
Bypass_Y_strainer x 2
DN50_Venturi_injector_8m3h_bypass x 2
Venturi suction port x 2
Bypass_manual_isolation_return x 2
Bypass_manual_isolation_return_handle x 2
Static_mixer_after_injection
Static_mixer_vane_1
Static_mixer_vane_2
Static_mixer_vane_3
Static_mixer_vane_4
Static_mixer_vane_5
Static_mixer_vane_6
pH_EC_flow_cell_after_mixer
Flow_cell_sample_in
Flow_cell_sample_out
pH_probe
EC_probe
Flow_cell_sample_takeoff
Flow_cell_sample_return
Fert_A_chemical_canister
Fert_A_suction_tube
Fert_A_suction_filter
Fert_A_service_valve
Fert_A_service_valve_handle
Fert_A_pulse_dosing_valve
Fert_A_pulse_dosing_valve solenoid coil
Fert_A_check_valve
Fert_A_feed_to_suction_manifold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

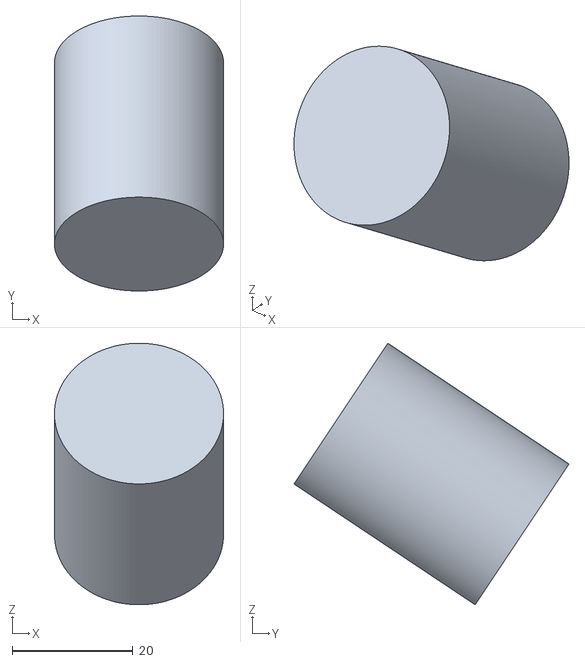
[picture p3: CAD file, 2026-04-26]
mechanical/printable_venturi_stl/Printable_venturi_suction_thread.stl
28.0 x 45.5 x 43.3

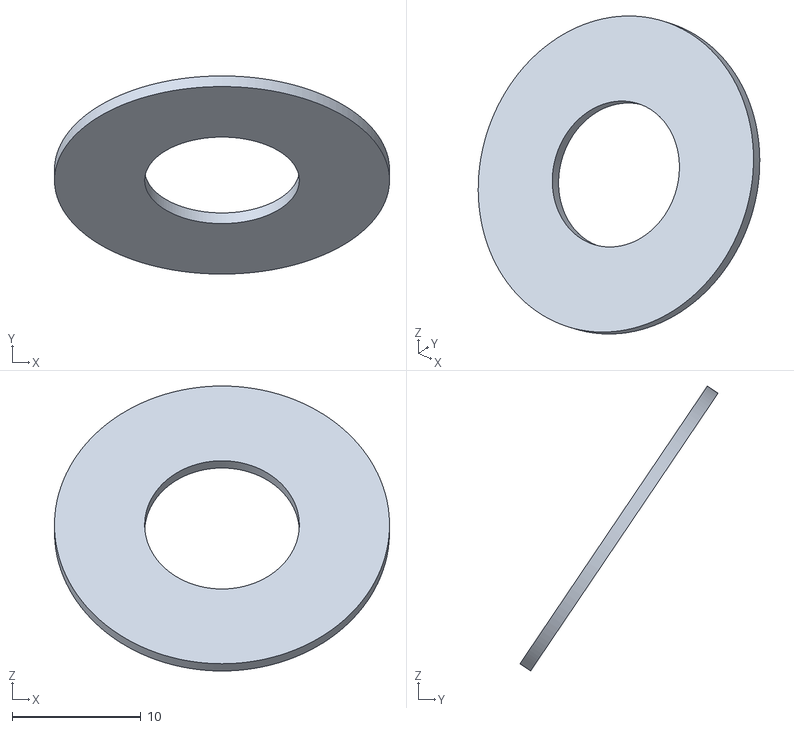
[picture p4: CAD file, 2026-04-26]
mechanical/printable_venturi_stl/Printable_venturi_suction_port.stl
26.0 x 15.4 x 22.1

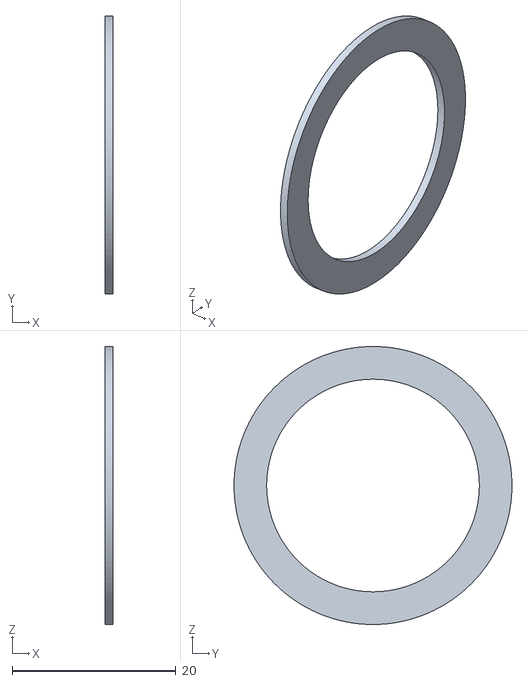
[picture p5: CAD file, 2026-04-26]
mechanical/printable_venturi_stl/Printable_throat_insert_26mm.stl
1.00 x 34.0 x 34.0

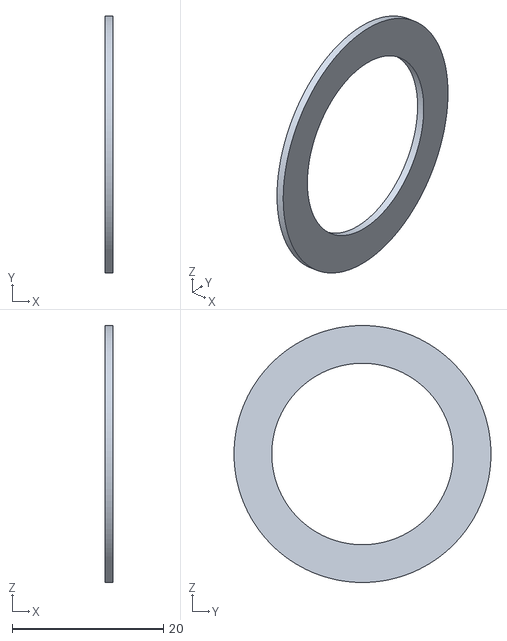
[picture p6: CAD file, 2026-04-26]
mechanical/printable_venturi_stl/Printable_throat_insert_24mm.stl
1.00 x 34.0 x 34.0

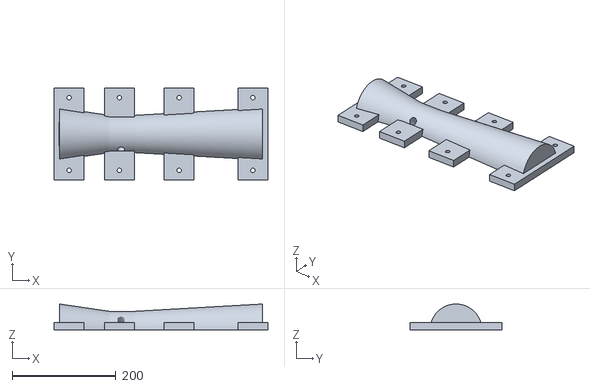
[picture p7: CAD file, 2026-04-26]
mechanical/printable_venturi_stl/Printable_venturi_upper_half.stl
412.0 x 178.0 x 50.0

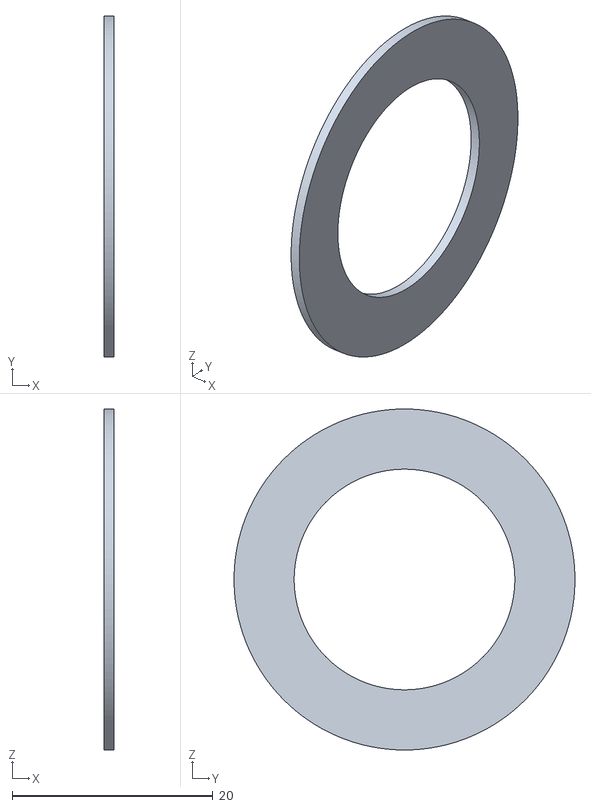
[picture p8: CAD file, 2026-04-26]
mechanical/printable_venturi_stl/Printable_throat_insert_22mm.stl
1.00 x 34.0 x 34.0

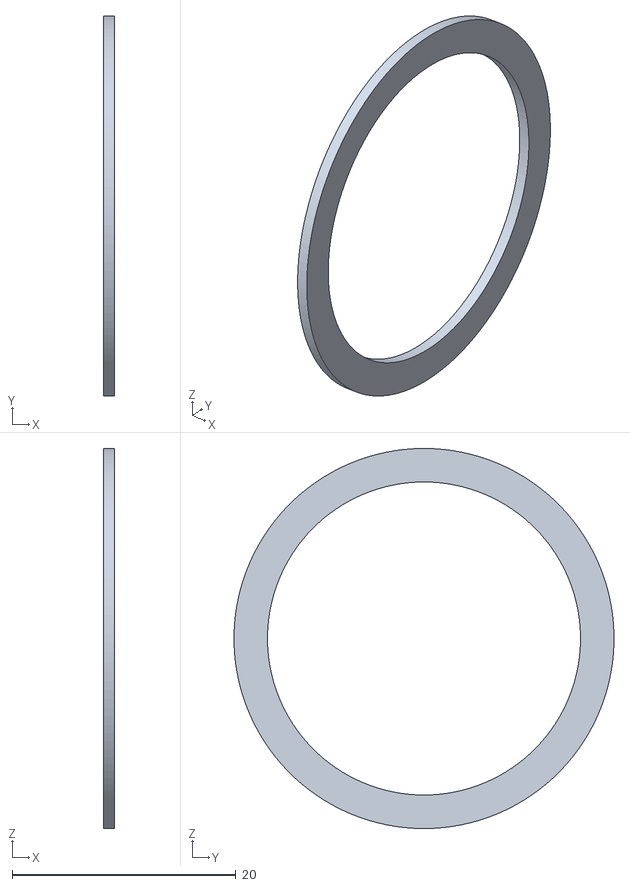
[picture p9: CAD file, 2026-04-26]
mechanical/printable_venturi_stl/Printable_throat_insert_28mm.stl
1.00 x 34.0 x 34.0

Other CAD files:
mechanical/printable_venturi_stl/Printable_venturi_lower_half.stl
mechanical/Irrigation_Venturi_Pulse_40m3h.FCStd

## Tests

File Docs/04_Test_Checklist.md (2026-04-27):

# STM32 Sulama Sistemi Test Checklist

Bu dokuman, kart uzerinde yapilacak temel dogrulama ve kabul testlerini takip etmek icin hazirlanmistir.

## 1. Derleme ve Programlama Oncesi

- [x] Proje warning'siz derleniyor
- [x] Uretilen `.elf` dosyasi olusuyor
- [x] Linker script dogru hedefi kullaniyor (`stm32/STM32F407VETX_FLASH.ld`)
- [x] MCU'ya flash islemi hatasiz tamamlandi
- [x] Kart yeniden baslatildiginda firmware aciliyor

## 2. Soguk Acilis ve Temel Baslangic

- [ ] Cihaz soguk acilista kilitlenmeden basliyor
- [ ] LCD acilisindan sonra ekran goruntu veriyor
- [ ] Splash ekranindan ana ekrana gecis oluyor
- [ ] Sistem ana ekrana dusebiliyor
- [ ] Acilista tum vanalar kapali durumda kaliyor
- [ ] EEPROM takili degilse veya okunamiyorsa sistem davranisi gozlenip not edildi

## 3. LCD ve GUI

- [ ] Ekranda pH ve EC alanlari gorunuyor
- [ ] Ana ekranda metinler okunakli
- [ ] Ekran yonu dogru
- [ ] Ekranda ciddi flicker veya bozulma yok
- [ ] Ana ekran periyodik olarak guncelleniyor
- [ ] Sistem beklemede iken durum mesaji dogru gorunuyor
- [ ] Sulama aktifken parsel bilgisi dogru gorunuyor
- [ ] Kalan sure alani mantikli degisiyor
- [ ] Ilerleme cubugu mevcut surec ile uyumlu gorunuyor

## 4. Touch ve Menu Akislari

- [ ] Touch basmalari tutarli algilaniyor
- [ ] Buton alanlari dogru yerlere tepki veriyor
- [ ] Yanlis koordinat veya kayma problemi yok
- [ ] Ana ekran -> Manuel ekran gecisi calisiyor
- [ ] Ana ekran -> Ayarlar ekran gecisi calisiyor
- [ ] Uzun kullanimda touch takili kalmiyor

## 5. Sensor Okumalari

- [ ] pH sensor verisi okunuyor
- [ ] EC sensor verisi okunuyor
- [ ] Sensor verileri ekranda anlamli aralikta gorunuyor
- [ ] Bagli olmayan sensor durumunda hata davranisi gozlendi
- [ ] Timeout durumunda sistem hata uretiyor
- [ ] Out-of-range durumda sistem hata uretiyor
- [ ] Sensor baglanti geri geldiginde toparlanma davranisi not edildi

## 6. Manuel Vana Kontrolu

- [ ] Her vana tek tek acilabiliyor
- [ ] Her vana tek tek kapatilabiliyor
- [ ] Yanlis vana tetiklenmiyor
- [ ] Bir vana kapatildiginda fiziksel cikis kapanıyor
- [ ] Manuel kullanimdan sonra sistem kararsiz duruma gecmiyor

## 7. Otomatik Sulama Akisi

- [ ] En az bir aktif parsel queue'ya alinabiliyor
- [ ] Otomatik sulama baslatilabiliyor
- [ ] Sensor kontrolu sonrasi sulama durumuna geciliyor
- [ ] Gecerli parsel vanasi aciliyor
- [ ] Parsel suresi tamamlaninca vana kapaniyor
- [ ] Queue'da siradaki parsel varsa bir sonrakine geciliyor
- [ ] Disabled parseller atlanıyor
- [ ] Ayni parsel queue'ya tekrar tekrar eklenmiyor
- [ ] Son parsel tamamlaninca sistem `IDLE` durumuna donuyor
- [ ] `FIXED_WINDOW` trigger modu eski pencere/gunde bir kez davranisini koruyor
- [ ] `PERIODIC` trigger modu `start_hhmm + anchor_offset_min` sonrasinda `period_min` aralikla tetikliyor
- [ ] `SUNRISE_PERIODIC` trigger modu ilk fazda `06:00 + anchor_offset_min` ankrajini kullaniyor
- [ ] `max_events_per_day` dolunca ayni gun yeni tetikleme baslamiyor
- [ ] Program basariyla baslamadan `last_run_day/minute` tuketilmiyor

## 8. pH / EC Dozaj ve Non-Blocking Davranis

- [ ] pH hedef disindayken uygun dozaj akisi basliyor
- [ ] EC hedef disindayken uygun dozaj akisi basliyor
- [ ] Dozaj sirasinda sistem tamamen donmuyor
- [ ] Dozaj sirasinda GUI guncellemesi devam ediyor
- [ ] Dozaj tamamlaninca vana kapaniyor
- [ ] Karistirma suresi tamamlaninca settling asamasina geciliyor
- [ ] `Settings > Params` ekraninda PH/EC sayfalari arasinda gecis yapiliyor
- [ ] `Settings > Params` ekraninda dozlama mantigi `FUZZY` / `LINEAR` olarak seciliyor
- [ ] `Settings > Params` uzerinden feedback, gain ve max cycle degerleri kaydediliyor
- [ ] `feedback_delay_ms` arttirildiginda yeniden dozlama karari gecikiyor
- [ ] `response_gain_percent` dusuruldugunde dozaj duty degeri daha yumusak artiyor
- [ ] pH hatasi buyudukce fuzzy duty kademeli artiyor
- [ ] pH hedefe yaklasirken fuzzy duty azalip overshoot yapmiyor
- [ ] EC hedefe yaklasirken fuzzy duty pH'a gore daha muhafazakar kaliyor
- [ ] Settling sonrasi hata azaliyorsa sonraki dozlama duty degeri yumusuyor
- [ ] `max_correction_cycles` asildiginda sistem fault davranisina geciyor
- [ ] Settling sonrasi sensorler yeniden kontrol ediliyor
- [ ] pH dusuk oldugunda baz duzeltme davranisi test edildi veya eksik olarak not edildi

## 9. Hata Yonetimi ve Emergency Stop

- [ ] Sensor hatasi durumunda sistem `ERROR` davranisina geciyor
- [ ] Error durumunda aktif dozaj vanasi kapaniyor
- [ ] Error durumunda queue temizleniyor
- [ ] Error durumunda tum vanalar guvenli sekilde kapaniyor
- [ ] Emergency stop tetiklenince tum vanalar kapaniyor
- [ ] Emergency stop sonrasi sistem beklenen state'te kaliyor
- [ ] Error/Emergency sonrasi yeniden baslatma veya tekrar calistirma davranisi dogrulandi

## 10. EEPROM ve Kalicilik

- [ ] Ilk acilista EEPROM formatlama davranisi dogru
- [x] Parametreler EEPROM'a yazilabiliyor
- [x] Yeniden baslatma sonrasi parametreler korunuyor
- [ ] Dozaj tepki parametreleri restart sonrasi EEPROM'dan geri yukleniyor
- [ ] Bozuk veri durumunda varsayilan degerlere donus davranisi test edildi
- [ ] CRC kontrolu beklendigi gibi calisiyor veya eksikligi not edildi
- [ ] Versiyon uyumsuzlugu davranisi test edildi veya eksikligi not edildi

## 11. Dayaniklilik ve Tekrar Testleri

- [ ] Ardisik 10 yeniden baslatmada sistem aciliyor
- [ ] Uzun sure acik kaldiginda sistem takilmiyor
- [ ] Ardisik manuel ac/kapat denemelerinde beklenmeyen durum olusmuyor
- [ ] Ardisik otomatik dongulerde state gecisleri bozulmuyor
- [ ] Sensor iletisimi kesilip geri geldiginde sistem toparlaniyor

## 12. Cikis Kriterleri

- [ ] Cihaz acilisinda ana ekran stabil geliyor
- [ ] Sensor degerleri ekranda anlamli sekilde gorunuyor
- [ ] Manuel modda vana ac/kapat calisiyor
- [ ] Otomatik modda en az 1 tam parsel dongusu tamamlandi
- [ ] Ayarlar yeniden baslatma sonrasi korundu
- [ ] Kritik hata durumunda tum vanalar guvenli sekilde kapandi

## 13. Test Notlari

- Test tarihi: 2026-04-25
- Test eden: Codex + DAPLink
- Kart revizyonu:
- Sensor tipi:
- Firmware build: `stm32/Debug/irrigation.elf`
- Notlar: `make -j4` guncel; OpenOCD CMSIS-DAP SWD baglantisi kuruldu, `program stm32/Debug/irrigation.elf verify reset exit` basarili, reset sonrasi CPU Thread modda calisti. USB CDC `PING` komutu `/dev/cu.usbmodem11102`, `/dev/tty.usbmodem11102` ve `/dev/cu.debug-console` uzerinden cevap vermedi; USB uygulama protokolu ayri incelenmeli.

- Test tarihi: 2026-04-27
- Test eden: Codex + Banana Pi `serapi`
- Kart revizyonu:
- Sensor tipi:
- Firmware build: `stm32/Debug/irrigation.elf`
- Notlar: Banana Pi uzerinden CMSIS-DAP OpenOCD 0.12.0 kuruldu ve `program /home/sera/irrigation.elf verify reset exit` basarili calisti. DAPLink mass-storage kopyalama `FAIL.TXT` icinde `The transfer timed out` verdigi icin SWD/OpenOCD yolu tercih edildi. Flash sonrasi Banana Pi USB hub'i yeniden enumerate edilince STM32 CDC `/dev/serial/by-id/usb-OktayCit_Irrigation_Controller_Config_Port_207E377C5232-if00` olarak geri geldi. Gateway `/health`, `/api/ping`, `/api/programs`, `/api/programs/1`, Program 8 `SET/GET`, flush alanlari ve gecersiz saat reddi dogrulandi. Program 1 test sirasinda gecici devre disi birakildi ve test sonunda eski etkin durumuna geri alindi.

- Test tarihi: 2026-04-27
- Test eden: Codex + Banana Pi `serapi`
- Kart revizyonu:
- Sensor tipi:
- Firmware build: `stm32/Debug/irrigation.elf`
- Notlar: Insight gateway protokol yuku Banana Pi uzerinden flash edildi ve OpenOCD verify/reset basarili tamamlandi. Gateway guncel `app.py` ile `0.0.0.0:8080` uzerinde yeniden baslatildi. `/api/device`, `/api/telemetry`, `/api/fault` ve `/api/runtime` endpointleri STM32 CDC uzerinden dogrulandi; ham cevaplar sirasiyla `OK,DEVICE`, `OK,TELEMETRY`, `OK,FAULT` ve `OK,RUNTIME` formatinda geldi. Program 1 flash/test sirasinda gecici devre disi birakildi ve test sonunda `enabled: 1` olarak eski degerleriyle dogrulandi.

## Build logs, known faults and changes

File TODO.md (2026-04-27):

# Irrigation Project TODO

Durum ozeti: Proje calisan ve warning'siz temiz derleme alan moduler firmware prototipi asamasinda. 2026-04-26 itibariyla core firmware yazilim mimarisi kapatilabilir durumda; `dosing_controller`, `parcel_scheduler`, `fault_manager`, `irrigation_runtime`, `irrigation_persistence`, `irrigation_schedule_trigger` ve `irrigation_run_session` katmanlari build icinde. Kalan kritik isler kart uzerinde runtime restore, vana/touch/sensor ve tam otomatik parsel dongusu dogrulamalaridir.

## Stratejik Referans

Bu dosya aktif uygulama listesi olarak kalir.

Segment bazli orta vade teknik backlog icin:

- [Docs/13_Teknik_Backlog.md](Docs/13_Teknik_Backlog.md)

Yol haritasi ve segment kararlari icin:

- [Docs/12_Urun_Yol_Haritasi.md](Docs/12_Urun_Yol_Haritasi.md)
- [Docs/11_Urun_Segmentasyonu.md](Docs/11_Urun_Segmentasyonu.md)
- [Docs/15_Turkiye_Pazar_Projeksiyon_Karsilastirmasi.md](Docs/15_Turkiye_Pazar_Projeksiyon_Karsilastirmasi.md)
- [Docs/16_Core_Kapanis_Checklist.md](Docs/16_Core_Kapanis_Checklist.md)
- [Docs/17_Insight_Raspbian_Arayuz_Plani.md](Docs/17_Insight_Raspbian_Arayuz_Plani.md)
- [Docs/18_BananaPi_Baglanti_Notlari.md](Docs/18_BananaPi_Baglanti_Notlari.md)
- [Docs/19_Internet_Tarimsal_Veriler_ve_Kamera_Plani.md](Docs/19_Internet_Tarimsal_Veriler_ve_Kamera_Plani.md)
- [Docs/20_Sera_Iklimlendirme_Plani.md](Docs/20_Sera_Iklimlendirme_Plani.md)

## Simdiki Sprint

### 2026-04-23 - Cekirdek Stabilizasyon
- [x] `HAL_Delay()` kullanan dozaj akislarini non-blocking state machine yapisina tasi
- [x] `dosing_controller`, `parcel_scheduler`, `fault_manager` ve runtime/persistence modullerini build icine al
- [x] Runtime backup yazarken aktif alarm bilgisini `FAULT_MGR` ile senkron tut
- [x] `irrigation_control.c` icindeki tekrar eden aktif-vana baslatma akisini `irrigation_run_session` yardimcilariyla azaltmaya basla
- [x] `irrigation_control.c` icindeki kalan scheduler / restore / persistence orkestrasyonunu daha da incelt
- [x] `CTRL_STATE_ERROR` ve `CTRL_STATE_EMERGENCY_STOP` reset akisini tekillestir
- [x] Runtime backup restore guard'larini firmware tarafinda sertlestir
- [x] DAPLink ile build flash/verify/reset smoke testini yap
- [ ] Aktif sulama sirasinda runtime backup ve reboot restore akisini kart uzerinde dogrula

### 2026-04-24 - GUI ve Operasyon Netligi
- [x] Ana ekrani gercek durum verileri ve kalan sure ile netlestir
- [x] Manuel vana kontrol ekranini tamamla
- [x] Alarm ekraninda fault / action metinlerini saha diliyle toparla
- [x] Placeholder ilerleme cubugunu gercek hesap ile degistir

### 2026-04-25 - Kalicilik ve Donanim
- [x] Sistem parametreleri icin CRC kontrolunu ve varsayilan fallback akisini sertlestir
- [x] GUI uzerinden degisen ayarlari EEPROM/flash katmanina kalici yaz
- [x] Yeniden baslatma sonrasi ayar koruma testini yap
- [x] pH/EC hedef dozlama icin fuzzy duty hesaplayiciyi ekle ve Params menusunden secilebilir yap
- [ ] Vana cikislarini, touch alanlarini ve sensor okumalarini kart uzerinde dogrula
- [ ] Turkiye pazari icin ticari ilk mekanik hedefi 4+1 Venturi/Z-bypass olarak prototiple
- [ ] Kanal basina 50-600 l/sa kapasite ve 1:100 / 1:200 dozlama profillerini veri modeline ekle

### 2026-04-26 - Insight Linux Edge Yon Degisikligi
- [x] `Insight` surum icin Raspbian/Raspberry Pi OS tarzi Linux edge arayuz kararini dokumante et
- [x] STM32 `device_info`, `telemetry_snapshot`, `fault_event` ve `runtime_event` paketlerini tanimla
- [x] USB CDC servis protokolunu gateway okuyabilecek sekilde genislet
- [ ] `gateway/` altinda device-agent + yerel API + SQLite store iskeletini baslat
- [ ] `gateway/ui` altinda canli dashboard prototipini hazirla

### 2026-04-27 - Internet Tarimsal Veri ve Kamera Destekli Insight
- [x] Ek sensor zorunlulugu olmadan konum, hava, urun donemi ve kamera destekli sulama karar mimarisini dokumante et
- [ ] Gateway `site_profile` ve `parcel_profile` veri modelini tasarla
- [ ] Hava/tarimsal veri provider adapter iskeletini ekle
- [ ] ET0, radyasyon, yagis ve sicaklik context verilerini SQLite store'a yaz
- [ ] Urun tipi ve donem tablosunu parsel recetelerine bagla
- [ ] `irrigation_advice` tavsiye modelini operator onayli akisla tasarla
- [ ] Kamera modulu icin `camera_observation` pipeline taslagini hazirla
- [ ] Context overlay ile sulama programi guncelleme limitlerini tanimla

### 2026-04-27 - Insight Sera Iklimlendirme
- [x] SCD41, DS18B20/1-Wire, PCF ve Modbus tabanli sera iklimlendirme planini dokumante et
- [ ] Gateway `climate-engine` servis veri modelini tasarla
- [ ] SCD41 I2C okuma adapter iskeletini ekle
- [ ] DS18B20/1-Wire sicaklik adapter iskeletini ekle
- [ ] VPD, dew point, CO2 durum sinifi ve iklim stres skorunu hesapla
- [ ] PCF8574/PCF8575 tabanli role/input genisleme modelini tanimla
- [ ] Modbus/RS485 iklim sensor/role modul adresleme modelini tasarla
- [ ] RS485/Modbus ultrasonik ruzgar hiz/yon sensoru adapter modelini ekle
- [ ] Iklim cikislarini vana/dozaj cikislarindan ayri `climate_actuator` sinifi olarak planla
- [ ] Fan, sisleme, golgeleme, isitma ve havalandirma interlock kurallarini tanimla

## Oncelik Sirasi

### P1
- [x] Sulama algoritmasini non-blocking hale getir
- [x] Emergency stop ve hata state gecislerini tek bir tutarli akis haline getir
- [ ] Parcel queue / siradaki parsel akisini tamamla ve otomatik modda en az 1 tam donguyu calistir
- [ ] Parsel vanalari ve dozaj vanalari icin saha kontrol MVP kapsamini adim adim uygula
- [x] Sulama akisini `pre-flush`, `dosing`, `post-flush` fazlarina ayir
- [ ] `Core` segment icin minimum donanim ve minimum ayar akisini sabitle
- [ ] `Core` ticari hidrolik hedefini 4+1 Venturi/Z-bypass ve 110 mm ana hat uyumu olarak sabitle
- [x] GUI temel akislarini tamamla
- [ ] Kart uzerinde temel donanim dogrulamasini yap

### P2
- [x] EEPROM kaliciligini saglamlastir
- [ ] Hata yonetimi ve guvenli kapanis akislarini tamamla
- [ ] Sensor hata senaryolarini test et
- [x] USB CDC `PING` cevapsizligini hedef USB/protokol tarafinda incele
- [ ] Touch kalibrasyonunu EEPROM ile yukle/kaydet akisi ile tamamla
- [ ] Program veri modelini statik saat alanlarindan `trigger_mode` ve flush parametrelerine dogru evrilt
- [ ] Program/ayar veri modeline kanal kapasitesi, dozlama orani ve nominal ana hat debisi alanlarini ekle
- [x] Basit mod icin gun dogumu/periyot tabanli tetikleme modelini tanimla
- [ ] `Core` ve Linux edge arayuzlu `Insight` icin feature flag veya urun seviyesi modelini tasarla
- [x] README ve TODO durumunu senkron tut

### P3
- [ ] Font ve gorsel iyilestirmeleri yap
- [ ] Gecmis/log ekranlarini ekle
- [ ] Kod temizligi ve dokumantasyon iyilestirmeleri yap
- [ ] LDR veya astronomik saat tabanli `light bucket` prototipini ekle
- [ ] Hedef hacim icin yazilimsal litre sayaci ve debi kalibrasyonunu ekle
- [ ] `Insight` segment icin Linux edge sensor zengin dashboard ve tani alanlarini tasarla
- [ ] `Insight` segment icin internet tarimsal veri ve kamera destekli context dashboardunu tasarla
- [ ] `Insight` segment icin sera iklim dashboardu ve climate-engine tasarimini baslat

## Cikis Kriterleri

- [ ] Cihaz acilisinda ana ekran stabil gelmeli
- [ ] Sensor degerleri ekranda anlamli sekilde gorunmeli
- [ ] Manuel modda vana ac/kapat calismali
- [ ] Otomatik modda en az 1 parsel dongusu tamamlanmali
- [x] Ayarlar yeniden baslatma sonrasi korunmali
- [ ] Kritik hata durumunda tum vanalar guvenli sekilde kapanmali

## Teknik Borclar

- [ ] Placeholder font tablolarini gercek font verileri ile degistir
- [ ] GUI cizimlerini tekrarli full redraw yerine daha kontrollu guncelle
- [ ] Sensor katmaninda kullanilmayan fonksiyon ve warning'leri temizle
- [x] `main.c` icindeki kullanilmayan board diagnostic/test fonksiyonlarini warning'siz build icin isaretle
- [ ] `.ioc` dosyasini repoya ekleme kararini netlestir
- [x] `CTRL_STATE_ERROR` ve `CTRL_STATE_EMERGENCY_STOP` akislarini teklestir
- [ ] `IRRIGATION_CTRL_AddToQueue` / queue doldurma ve bosaltma akislarini netlestir
- [ ] `irrigation_control.c` icindeki scheduler, dosing, restore ve persistence sorumluluklarini ayristir
- [x] EEPROM load sirasinda CRC ve versiyon dogrulamasini zorunlu hale getir
- [ ] Touch kalibrasyon stub fonksiyonlarini gercek implementasyona cevir
- [ ] `rtc_driver_stub.c` ve `hw_crc_stub.c` yerine hedef kart suruculerini bagla
- [ ] Multi-zone parsel bazli recete modeli ile global recete modelinin ayrimini netlestir
- [ ] Tek kod tabaninda iki urun seviyesini surdurmenin konfig yapisini netlestir

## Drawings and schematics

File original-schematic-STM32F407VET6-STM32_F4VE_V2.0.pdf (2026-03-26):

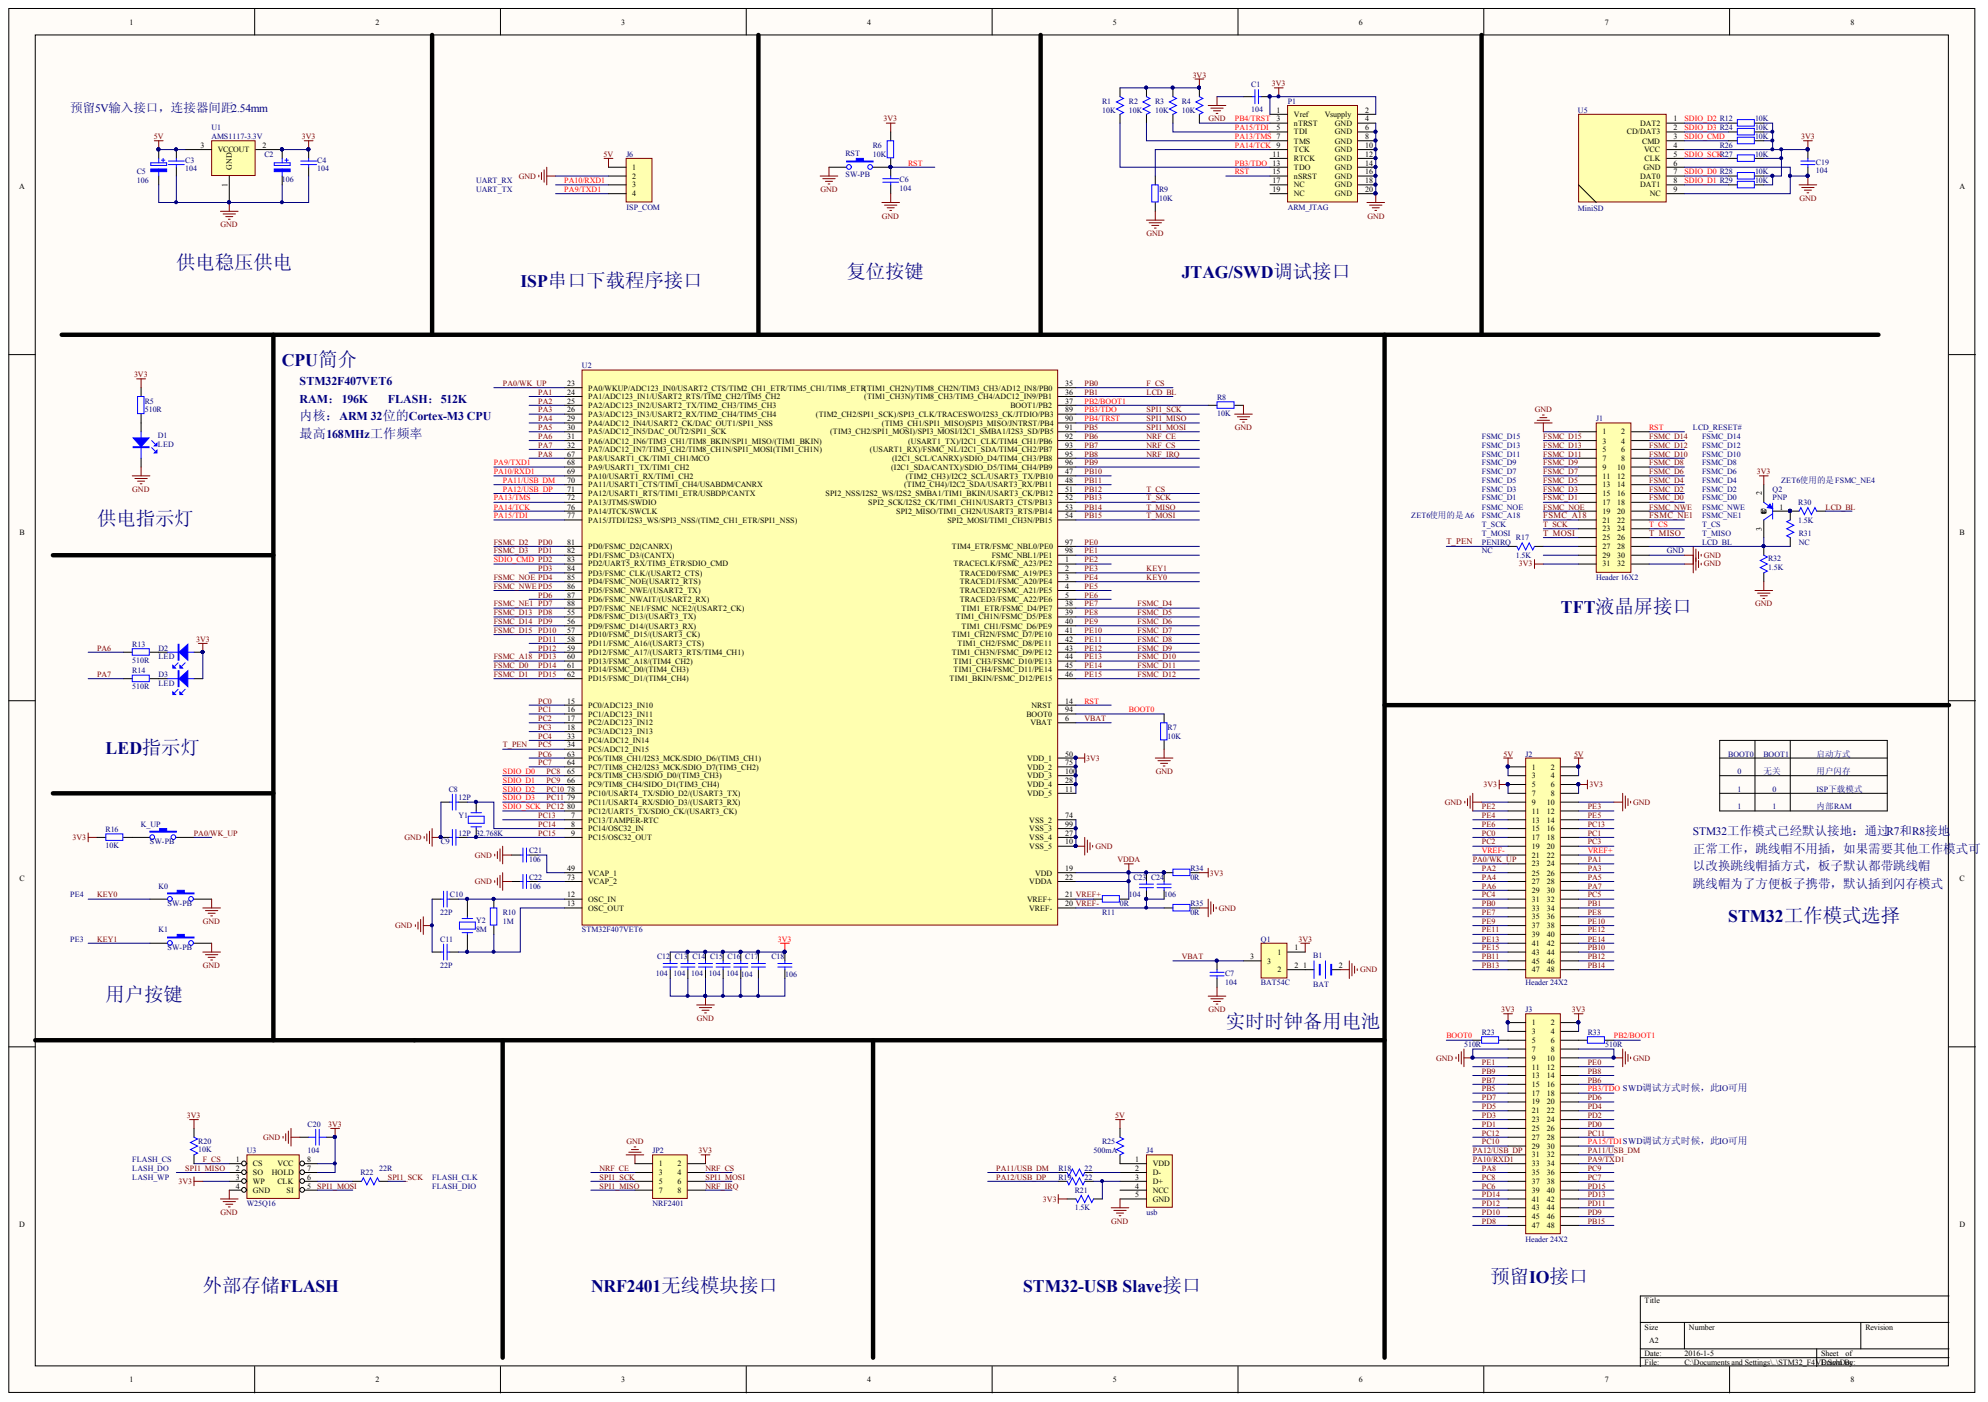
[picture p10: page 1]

SDIO_SCK PC12 | PC12/UART5_TX/SDIO_CK/(USART3_CK) 80

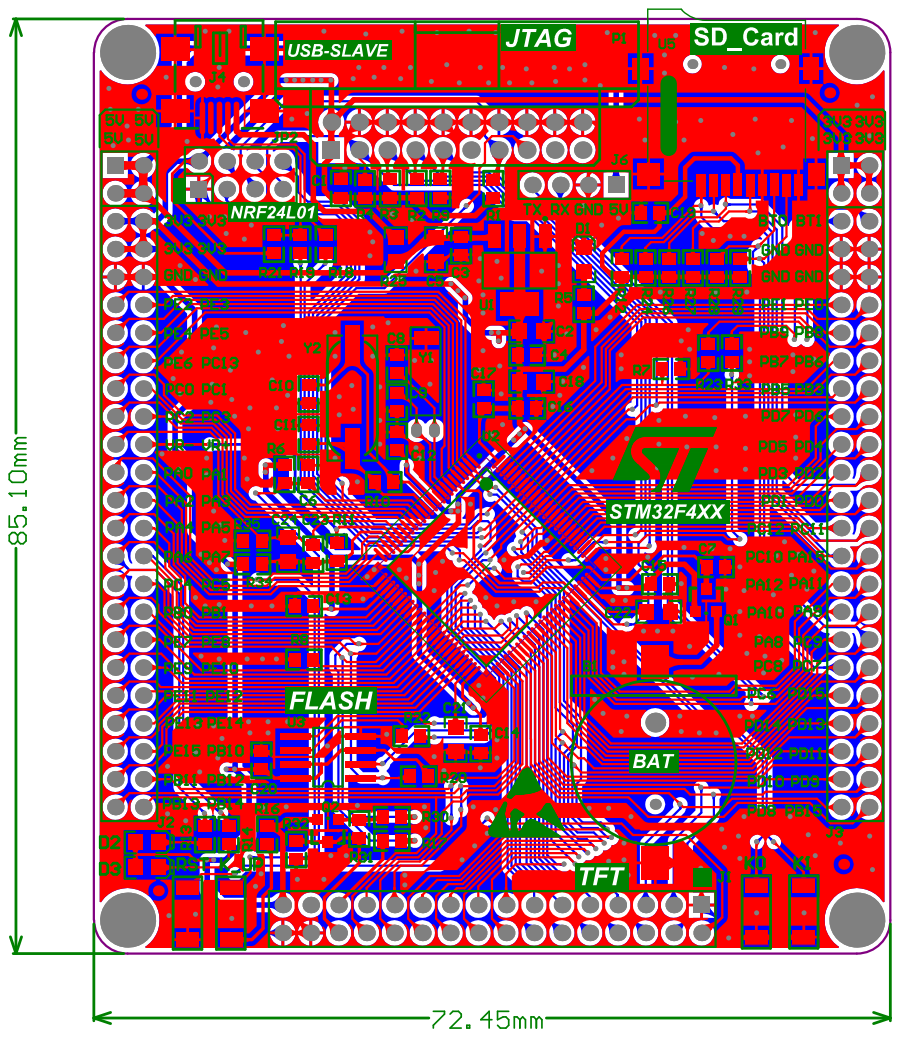
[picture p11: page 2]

Comment | Description | Designator | Footprint | LibRef | Quantity
BAT | | B1 | BAT | BATTERY | 1
104 | Capacitor, Capacitor, Capacitor, Capacitor, Capacitor, Capacitor, Capacitor, Capacitor, Capacitor, Capacitor, Capacitor, Capacitor aSemiconductor SIM Model), [Notialue], Capacitor | C1, C3, C4, C6, C7, C12, C13, C14, C15, C16, C17, C19, C20, C23 | RC0603 | Cap, CAP, CAP, CAP, Cap, Cap, Cap, Cap, Cap, Cap, Cap, Cap Semi, CAP, Cap | 14
106 | [Notialue], [Notialue], Capacitor, Capacitor, Capacitor, Capacitor | C2, C5, C18, C21, C22, C24 | RC0805 | ELECTRO2, ELECTRO2, Cap, Cap, Cap, Cap | 6
12P | | C8, C9 | RC0603 | CAP | 2
22P | Capacitor | C10, C11 | RC0603 | CAP | 2
LED | | D1, D2, D3 | LED0805 | LED | 3
Header 16X2 | Header, 16-Pin, Dual row | J1 | IDE2X16 | Header 16X2 | 1
Header 24X2 | Header, 24-Pin, Dual row | J2, J3 | IDE2X24 | Header 24X2 | 2
usb | | J4 | Mini_USB | usb | 1
ISP_COM | Header, 4-Pin | J6 | HDR1X4 | Header 4 | 1
NRF2401 | Header, 4-Pin, Dual row | JP2 | IDE2X4 | Header 4X2 | 1
SW-PB | | K0, K1, K_UP, RST | SW-SPST | SW-PB | 4
ARM_JTAG | JTAG | P1 | JTAG-20P | JTAG | 1
BAT54C | | Q1 | SOT-23-BAT54C | BAT54C | 1
PNP | PNP Bipolar Transistor | Q2 | PNP_SOT23 | PNP | 1
10K | [Notialue], [Notialue], [Notialue], [Notialue], Resistor, Resistor, Resistor, Resistor, Resistor, Resistor, [Notialue], Resistor, Resistor, Resistor, Resistor, Resistor | R1, R2, R3, R4, R6, R7, R8, R9, R12, R16, R20, R24, R26, R27, R28, R29 | RC0603 | RES, RES, RES, RES, Res2, Res2, Res2, Res2, Res2, Res2, RES, Res2, Res2, Res2, Res2, Res2 | 16
510R | Resistor | R5, R13, R14, R23, R33 | RC0603 | Res2 | 5
1M | Resistor | R10 | RC0603 | Res2 | 1
0R | Resistor | R11, R34, R35 | RC0603 | Res2 | 3
1.5K | | R17, R21, R30, R32 | RC0603 | RES | 4
22 | | R18, R19 | RC0603 | RES | 2
22R | | R22 | RC0603 | RES | 1
500mA | | R25 | RC0805 | RES | 1
NC | | R31 | RC0603 | RES | 1
AMS1117-3.3V | | U1 | SOT-223 | 11 | 1
STM32F407VET6 | | U2 | | STM32F407VET6 | 1
W25Q16 | | U3 | SOP8L | W25X16 | 1
MiniSD | | U5 | TF_SD | MiniSD | 1
32.768K | 晶振 | Y1 | JZ32768 | CRYSTAL | 1
8M | Crystal | Y2 | 49S_SMD | CRYSTAL | 1

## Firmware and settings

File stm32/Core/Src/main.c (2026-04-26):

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
/* Includes ------------------------------------------------------------------*/
#include "main.h"

/* USER CODE BEGIN PM */
#if defined(__GNUC__)
#define BOARD_DIAG_UNUSED __attribute__((unused))
#else
#define BOARD_DIAG_UNUSED
#endif

/* USER CODE END PM */

ADC_HandleTypeDef hadc1;
DMA_HandleTypeDef hdma_adc1;

I2C_HandleTypeDef hi2c1;
DMA_HandleTypeDef hdma_i2c1_rx;
DMA_HandleTypeDef hdma_i2c1_tx;

SPI_HandleTypeDef hspi1;
SPI_HandleTypeDef hspi2;

TIM_HandleTypeDef htim1;
TIM_HandleTypeDef htim2;
TIM_HandleTypeDef htim3;
TIM_HandleTypeDef htim4;

UART_HandleTypeDef huart1;
DMA_HandleTypeDef hdma_usart1_rx;
DMA_HandleTypeDef hdma_usart1_tx;

NOR_HandleTypeDef hnor1;

/* Stubbed - HAL driver not available */
/* CRC_HandleTypeDef hcrc; */
/* RTC_HandleTypeDef hrtc; */

/* USER CODE BEGIN PV */

/* ADC DMA Buffer for continuous conversion */
volatile uint16_t g_adc_dma_buffer[ADC_DMA_BUFFER_SIZE] = {0};
volatile uint8_t g_adc_conversion_complete = 0;

/* System tick counter from TIM3 */
volatile uint32_t g_system_tick = 0;

/* USER CODE END PV */

void SystemClock_Config(void);
static void MX_GPIO_Init(void);
static void MX_ADC1_Init(void);
static void MX_FSMC_Init(void);
static void MX_I2C1_Init(void);
static void MX_SPI1_Init(void);
static void MX_SPI2_Init(void);
static void MX_TIM1_Init(void);
static void MX_USART1_UART_Init(void);
static void MX_TIM2_Init(void);
static void MX_TIM3_Init(void);
static void MX_TIM4_Init(void);
static void MX_CRC_Init(void);
static void MX_RTC_Init(void);
/* USER CODE BEGIN PFP */
static void BOARD_LED_DiagnosticInit(void) BOARD_DIAG_UNUSED;
static void BOARD_LED_DiagnosticLoop(void) BOARD_DIAG_UNUSED;
static void BOARD_LCD_TestLoop(void) BOARD_DIAG_UNUSED;
static void BOARD_LCD_ProbeLoop(void) BOARD_DIAG_UNUSED;
static void BOARD_LCD_SweepLoop(void) BOARD_DIAG_UNUSED;
static void BOARD_LCD_ForceBacklightDefaultState(void) BOARD_DIAG_UNUSED;
static void BOARD_IrrigationDemoInit(void) BOARD_DIAG_UNUSED;
static void BOARD_IrrigationDemoProcess(void) BOARD_DIAG_UNUSED;

/* USER CODE END PFP */

/* USER CODE BEGIN 0 */
volatile uint16_t g_lcd_probe_words[96] = {0};
volatile uint32_t g_lcd_probe_signature = 0U;
volatile uint32_t g_lcd_sweep_profile = 0U;

typedef struct {
  uint8_t active;
  uint8_t valve_id;
  uint8_t phase;
  uint32_t phase_start_tick;
} board_irrigation_demo_t;

static board_irrigation_demo_t g_board_irrigation_demo = {0};

typedef struct {
  const char *name;
  uint32_t data_offset;
  GPIO_PinState pb10_state;
  lcd_color_t color;
  void (*init_fn)(uint32_t data_offset);
} board_lcd_sweep_profile_t;

static inline void BOARD_LCD_WriteCommandAt(uint32_t data_offset, uint16_t cmd)
{
  (void)data_offset;
  *(volatile uint16_t *)LCD_BASE_ADDR = cmd;
  __asm volatile("nop");
  __asm volatile("nop");
}

static inline void BOARD_LCD_WriteDataAt(uint32_t data_offset, uint16_t data)
{
  *(volatile uint16_t *)(LCD_BASE_ADDR + data_offset) = data;
  __asm volatile("nop");
  __asm volatile("nop");
}

static void BOARD_LCD_WriteRegAt(uint32_t data_offset, uint16_t reg,
                                 uint16_t data)
{
  BOARD_LCD_WriteCommandAt(data_offset, reg);
  BOARD_LCD_WriteDataAt(data_offset, data);
}

static void BOARD_LCD_ILI9341_InitAt(uint32_t data_offset)
{
  BOARD_LCD_WriteCommandAt(data_offset, 0x01);
  HAL_Delay(10);

  BOARD_LCD_WriteCommandAt(data_offset, 0xCB);
  BOARD_LCD_WriteDataAt(data_offset, 0x39);
  BOARD_LCD_WriteDataAt(data_offset, 0x2C);
  BOARD_LCD_WriteDataAt(data_offset, 0x00);
  BOARD_LCD_WriteDataAt(data_offset, 0x34);
  BOARD_LCD_WriteDataAt(data_offset, 0x02);

  BOARD_LCD_WriteCommandAt(data_offset, 0xCF);
  BOARD_LCD_WriteDataAt(data_offset, 0x00);
  BOARD_LCD_WriteDataAt(data_offset, 0xC1);
  BOARD_LCD_WriteDataAt(data_offset, 0x30);

  BOARD_LCD_WriteCommandAt(data_offset, 0xE8);
  BOARD_LCD_WriteDataAt(data_offset, 0x85);
  BOARD_LCD_WriteDataAt(data_offset, 0x00);
  BOARD_LCD_WriteDataAt(data_offset, 0x78);

  BOARD_LCD_WriteCommandAt(data_offset, 0xEA);
  BOARD_LCD_WriteDataAt(data_offset, 0x00);
  BOARD_LCD_WriteDataAt(data_offset, 0x00);

  BOARD_LCD_WriteCommandAt(data_offset, 0xED);
  BOARD_LCD_WriteDataAt(data_offset, 0x64);
  BOARD_LCD_WriteDataAt(data_offset, 0x03);
  BOARD_LCD_WriteDataAt(data_offset, 0x12);
  BOARD_LCD_WriteDataAt(data_offset, 0x81);

  BOARD_LCD_WriteCommandAt(data_offset, 0xF7);
  BOARD_LCD_WriteDataAt(data_offset, 0x20);

  BOARD_LCD_WriteCommandAt(data_offset, 0xC0);
  BOARD_LCD_WriteDataAt(data_offset, 0x23);
  BOARD_LCD_WriteCommandAt(data_offset, 0xC1);
  BOARD_LCD_WriteDataAt(data_offset, 0x10);

  BOARD_LCD_WriteCommandAt(data_offset, 0xC5);
  BOARD_LCD_WriteDataAt(data_offset, 0x3E);
  BOARD_LCD_WriteDataAt(data_offset, 0x28);
  BOARD_LCD_WriteCommandAt(data_offset, 0xC7);
  BOARD_LCD_WriteDataAt(data_offset, 0x86);

  BOARD_LCD_WriteCommandAt(data_offset, 0x36);
  BOARD_LCD_WriteDataAt(data_offset, 0x48);
  BOARD_LCD_WriteCommandAt(data_offset, 0x3A);
  BOARD_LCD_WriteDataAt(data_offset, 0x55);

  BOARD_LCD_WriteCommandAt(data_offset, 0xB1);
  BOARD_LCD_WriteDataAt(data_offset, 0x00);
  BOARD_LCD_WriteDataAt(data_offset, 0x18);

  BOARD_LCD_WriteCommandAt(data_offset, 0xB6);
  BOARD_LCD_WriteDataAt(data_offset, 0x08);
  BOARD_LCD_WriteDataAt(data_offset, 0x82);
  BOARD_LCD_WriteDataAt(data_offset, 0x27);

  BOARD_LCD_WriteCommandAt(data_offset, 0xF2);
  BOARD_LCD_WriteDataAt(data_offset, 0x00);
  BOARD_LCD_WriteCommandAt(data_offset, 0x26);
  BOARD_LCD_WriteDataAt(data_offset, 0x01);

  BOARD_LCD_WriteCommandAt(data_offset, 0xE0);
  BOARD_LCD_WriteDataAt(data_offset, 0x0F);
  BOARD_LCD_WriteDataAt(data_offset, 0x31);
  BOARD_LCD_WriteDataAt(data_offset, 0x2B);
  BOARD_LCD_WriteDataAt(data_offset, 0x0C);
  BOARD_LCD_WriteDataAt(data_offset, 0x0E);
  BOARD_LCD_WriteDataAt(data_offset, 0x08);
  BOARD_LCD_WriteDataAt(data_offset, 0x4E);
  BOARD_LCD_WriteDataAt(data_offset, 0xF1);
  BOARD_LCD_WriteDataAt(data_offset, 0x37);
  BOARD_LCD_WriteDataAt(data_offset, 0x07);
  BOARD_LCD_WriteDataAt(data_offset, 0x10);
  BOARD_LCD_WriteDataAt(data_offset, 0x03);
  BOARD_LCD_WriteDataAt(data_offset, 0x0E);
  BOARD_LCD_WriteDataAt(data_offset, 0x09);
  BOARD_LCD_WriteDataAt(data_offset, 0x00);

  BOARD_LCD_WriteCommandAt(data_offset, 0xE1);
  BOARD_LCD_WriteDataAt(data_offset, 0x00);
  BOARD_LCD_WriteDataAt(data_offset, 0x0E);
  BOARD_LCD_WriteDataAt(data_offset, 0x14);
  BOARD_LCD_WriteDataAt(data_offset, 0x03);
  BOARD_LCD_WriteDataAt(data_offset, 0x11);
  BOARD_LCD_WriteDataAt(data_offset, 0x07);
  BOARD_LCD_WriteDataAt(data_offset, 0x31);
  BOARD_LCD_WriteDataAt(data_offset, 0xC1);
  BOARD_LCD_WriteDataAt(data_offset, 0x48);
  BOARD_LCD_WriteDataAt(data_offset, 0x08);
  BOARD_LCD_WriteDataAt(data_offset, 0x0F);
  BOARD_LCD_WriteDataAt(data_offset, 0x0C);
  BOARD_LCD_WriteDataAt(data_offset, 0x31);
  BOARD_LCD_WriteDataAt(data_offset, 0x36);
  BOARD_LCD_WriteDataAt(data_offset, 0x0F);

  BOARD_LCD_WriteCommandAt(data_offset, 0x11);
  HAL_Delay(120);
  BOARD_LCD_WriteCommandAt(data_offset, 0x29);

  BOARD_LCD_WriteCommandAt(data_offset, 0x2A);
  BOARD_LCD_WriteDataAt(data_offset, 0x00);
  BOARD_LCD_WriteDataAt(data_offset, 0x00);
  BOARD_LCD_WriteDataAt(data_offset, 0x00);
  BOARD_LCD_WriteDataAt(data_offset, 0xEF);
  BOARD_LCD_WriteCommandAt(data_offset, 0x2B);
  BOARD_LCD_WriteDataAt(data_offset, 0x00);
  BOARD_LCD_WriteDataAt(data_offset, 0x00);
  BOARD_LCD_WriteDataAt(data_offset, 0x01);
  BOARD_LCD_WriteDataAt(data_offset, 0x3F);
}

static void BOARD_LCD_ILI9341_FillAt(uint32_t data_offset, lcd_color_t color)
{
  uint32_t i = 0U;

  BOARD_LCD_WriteCommandAt(data_offset, 0x2C);
  for (i = 0U; i < (240UL * 320UL); i++) {
    BOARD_LCD_WriteDataAt(data_offset, color);
  }
}

static void BOARD_LCD_ILI9325_InitAt(uint32_t data_offset)
{
  BOARD_LCD_WriteRegAt(data_offset, 0x00E5, 0x8000);
  BOARD_LCD_WriteRegAt(data_offset, 0x0000, 0x0001);
  BOARD_LCD_WriteRegAt(data_offset, 0x0001, 0x0100);
  BOARD_LCD_WriteRegAt(data_offset, 0x0002, 0x0700);
  BOARD_LCD_WriteRegAt(data_offset, 0x0003, 0x1030);
  BOARD_LCD_WriteRegAt(data_offset, 0x0004, 0x0000);
  BOARD_LCD_WriteRegAt(data_offset, 0x0008, 0x0202);
  BOARD_LCD_WriteRegAt(data_offset, 0x0009, 0x0000);
  BOARD_LCD_WriteRegAt(data_offset, 0x000A, 0x0000);
  BOARD_LCD_WriteRegAt(data_offset, 0x000C, 0x0000);
  BOARD_LCD_WriteRegAt(data_offset, 0x000D, 0x0000);
  BOARD_LCD_WriteRegAt(data_offset, 0x000F, 0x0000);
  BOARD_LCD_WriteRegAt(data_offset, 0x0010, 0x0000);
  BOARD_LCD_WriteRegAt(data_offset, 0x0011, 0x0007);
  BOARD_LCD_WriteRegAt(data_offset, 0x0012, 0x0000);
  BOARD_LCD_WriteRegAt(data_offset, 0x0013, 0x0000);
  HAL_Delay(50);

  BOARD_LCD_WriteRegAt(data_offset, 0x0010, 0x1690);
  BOARD_LCD_WriteRegAt(data_offset, 0x0011, 0x0227);
  HAL_Delay(50);
  BOARD_LCD_WriteRegAt(data_offset, 0x0012, 0x001D);
  HAL_Delay(50);
  BOARD_LCD_WriteRegAt(data_offset, 0x0013, 0x1500);
  BOARD_LCD_WriteRegAt(data_offset, 0x0029, 0x0018);
  BOARD_LCD_WriteRegAt(data_offset, 0x002B, 0x000D);
  HAL_Delay(50);

  BOARD_LCD_WriteRegAt(data_offset, 0x0020, 0x0000);
  BOARD_LCD_WriteRegAt(data_offset, 0x0021, 0x0000);
  BOARD_LCD_WriteRegAt(data_offset, 0x0050, 0x0000);
  BOARD_LCD_WriteRegAt(data_offset, 0x0051, 0x00EF);
  BOARD_LCD_WriteRegAt(data_offset, 0x0052, 0x0000);
  BOARD_LCD_WriteRegAt(data_offset, 0x0053, 0x013F);
  BOARD_LCD_WriteRegAt(data_offset, 0x0060, 0xA700);
  BOARD_LCD_WriteRegAt(data_offset, 0x0061, 0x0001);
  BOARD_LCD_WriteRegAt(data_offset, 0x006A, 0x0000);
  BOARD_LCD_WriteRegAt(data_offset, 0x0080, 0x0000);
  BOARD_LCD_WriteRegAt(data_offset, 0x0081, 0x0000);
  BOARD_LCD_WriteRegAt(data_offset, 0x0082, 0x0000);
  BOARD_LCD_WriteRegAt(data_offset, 0x0083, 0x0000);
  BOARD_LCD_WriteRegAt(data_offset, 0x0084, 0x0000);
  BOARD_LCD_WriteRegAt(data_offset, 0x0085, 0x0000);
  BOARD_LCD_WriteRegAt(data_offset, 0x0090, 0x0010);
  BOARD_LCD_WriteRegAt(data_offset, 0x0092, 0x0600);
  BOARD_LCD_WriteRegAt(data_offset, 0x0093, 0x0003);
  BOARD_LCD_WriteRegAt(data_offset, 0x0095, 0x0110);
  BOARD_LCD_WriteRegAt(data_offset, 0x0097, 0x0000);
  BOARD_LCD_WriteRegAt(data_offset, 0x0098, 0x0000);
  BOARD_LCD_WriteRegAt(data_offset, 0x0007, 0x0173);
}

static void BOARD_LCD_ILI9325_FillAt(uint32_t data_offset, lcd_color_t color)
{
  uint32_t i = 0U;

  BOARD_LCD_WriteRegAt(data_offset, 0x0020, 0x0000);
  BOARD_LCD_WriteRegAt(data_offset, 0x0021, 0x0000);
  BOARD_LCD_WriteCommandAt(data_offset, 0x0022);
  for (i = 0U; i < (240UL * 320UL); i++) {
    BOARD_LCD_WriteDataAt(data_offset, color);
  }
}

static void BOARD_LCD_SSD1289_InitAt(uint32_t data_offset)
{
  BOARD_LCD_WriteRegAt(data_offset, 0x0000, 0x0001);
  BOARD_LCD_WriteRegAt(data_offset, 0x0003, 0xA8A4);
  BOARD_LCD_WriteRegAt(data_offset, 0x000C, 0x0000);
  BOARD_LCD_WriteRegAt(data_offset, 0x000D, 0x080C);
  BOARD_LCD_WriteRegAt(data_offset, 0x000E, 0x2B00);
  BOARD_LCD_WriteRegAt(data_offset, 0x001E, 0x00B7);
  BOARD_LCD_WriteRegAt(data_offset, 0x0001, 0x2B3F);
  BOARD_LCD_WriteRegAt(data_offset, 0x0002, 0x0600);
  BOARD_LCD_WriteRegAt(data_offset, 0x0010, 0x0000);
  BOARD_LCD_WriteRegAt(data_offset, 0x0011, 0x6070);
  BOARD_LCD_WriteRegAt(data_offset, 0x0005, 0x0000);
  BOARD_LCD_WriteRegAt(data_offset, 0x0006, 0x0000);
  BOARD_LCD_WriteRegAt(data_offset, 0x0016, 0xEF1C);
  BOARD_LCD_WriteRegAt(data_offset, 0x0017, 0x0003);
  BOARD_LCD_WriteRegAt(data_offset, 0x0007, 0x0233);
  BOARD_LCD_WriteRegAt(data_offset, 0x000B, 0x0000);
  BOARD_LCD_WriteRegAt(data_offset, 0x000F, 0x0000);
  BOARD_LCD_WriteRegAt(data_offset, 0x0041, 0x0000);
  BOARD_LCD_WriteRegAt(data_offset, 0x0042, 0x0000);
  BOARD_LCD_WriteRegAt(data_offset, 0x0048, 0x0000);
  BOARD_LCD_WriteRegAt(data_offset, 0x0049, 0x013F);
  BOARD_LCD_WriteRegAt(data_offset, 0x004A, 0x0000);
  BOARD_LCD_WriteRegAt(data_offset, 0x004B, 0x0000);
  BOARD_LCD_WriteRegAt(data_offset, 0x0044, 0xEF00);
  BOARD_LCD_WriteRegAt(data_offset, 0x0045, 0x0000);
  BOARD_LCD_WriteRegAt(data_offset, 0x0046, 0x013F);
}

static void BOARD_LCD_SSD1289_FillAt(uint32_t data_offset, lcd_color_t color)
{
  uint32_t i = 0U;

  BOARD_LCD_WriteRegAt(data_offset, 0x004E, 0x0000);
  BOARD_LCD_WriteRegAt(data_offset, 0x004F, 0x0000);
  BOARD_LCD_WriteCommandAt(data_offset, 0x0022);
  for (i = 0U; i < (240UL * 320UL); i++) {
    BOARD_LCD_WriteDataAt(data_offset, color);
  }
}

static void BOARD_LCD_ProbeRead(uint8_t reg, uint32_t base_index,
                                uint32_t samples)
{
  uint32_t i = 0U;

  if ((base_index + samples + 1U) > (sizeof(g_lcd_probe_words) /
                                     sizeof(g_lcd_probe_words[0]))) {
    return;
  }

  g_lcd_probe_words[base_index] = reg;
  LCD_WriteCommand(reg);
  (void)LCD_ReadData16(); /* dummy read */

  for (i = 0U; i < samples; i++) {
    g_lcd_probe_words[base_index + 1U + i] = LCD_ReadData16();
  }
}

static void BOARD_LED_DiagnosticInit(void)
{
  GPIO_InitTypeDef GPIO_InitStruct = {0};

  __HAL_RCC_GPIOA_CLK_ENABLE();

  /*
   * D2 and D3 are wired to PA6/PA7 as active-low LEDs on this board.
   * Drive them high first so the board powers up with both LEDs off.
   */
  HAL_GPIO_WritePin(GPIOA, GPIO_PIN_6 | GPIO_PIN_7, GPIO_PIN_SET);

  GPIO_InitStruct.Pin = GPIO_PIN_6 | GPIO_PIN_7;
  GPIO_InitStruct.Mode = GPIO_MODE_OUTPUT_PP;
  GPIO_InitStruct.Pull = GPIO_NOPULL;
  GPIO_InitStruct.Speed = GPIO_SPEED_FREQ_LOW;
  HAL_GPIO_Init(GPIOA, &GPIO_InitStruct);
}

static void BOARD_LED_DiagnosticLoop(void)
{
  while (1)
  {
    HAL_GPIO_WritePin(GPIOA, GPIO_PIN_6, GPIO_PIN_RESET);
    HAL_GPIO_WritePin(GPIOA, GPIO_PIN_7, GPIO_PIN_SET);
    HAL_Delay(200);

    HAL_GPIO_WritePin(GPIOA, GPIO_PIN_6, GPIO_PIN_SET);
    HAL_GPIO_WritePin(GPIOA, GPIO_PIN_7, GPIO_PIN_RESET);
    HAL_Delay(200);
  }
}
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
int main(void)
{
  uint32_t last_status_update = 0;
  uint32_t last_task_tick = 0;
  uint8_t validation_counter = 0U;

  /* MCU Configuration--------------------------------------------------------*/

  /* Reset of all peripherals, Initializes the Flash interface and the Systick. */
  HAL_Init();

  /* Configure the system clock */
  SystemClock_Config();

  /* Initialize all configured peripherals */
  MX_GPIO_Init();
#if !BOARD_LED_DIAGNOSTIC_MODE && !BOARD_LCD_TEST_MODE && !BOARD_LCD_PROBE_MODE && !BOARD_LCD_SWEEP_MODE
  MX_ADC1_Init();
  MX_FSMC_Init();
  MX_I2C1_Init();
  MX_SPI1_Init();
  MX_SPI2_Init();
  MX_TIM1_Init();
  MX_USART1_UART_Init();
  MX_TIM2_Init();
  MX_TIM3_Init();
  MX_TIM4_Init();
  MX_CRC_Init();
  MX_RTC_Init();
#elif BOARD_LCD_TEST_MODE || BOARD_LCD_PROBE_MODE || BOARD_LCD_SWEEP_MODE
  MX_FSMC_Init();
  MX_TIM1_Init();
#endif
  /* USER CODE BEGIN 2 */
#if BOARD_LED_DIAGNOSTIC_MODE
  BOARD_LED_DiagnosticInit();
  BOARD_LED_DiagnosticLoop();
#elif BOARD_LCD_TEST_MODE
  if (HAL_TIM_PWM_Start(&htim1, TIM_CHANNEL_1) != HAL_OK)
  {
    Error_Handler();
  }

  LCD_SetBacklight(100);
  LCD_Init();
  BOARD_LCD_TestLoop();
#elif BOARD_LCD_PROBE_MODE
  if (HAL_TIM_PWM_Start(&htim1, TIM_CHANNEL_1) != HAL_OK)
  {
    Error_Handler();
  }

  LCD_SetBacklight(100);
  BOARD_LCD_ProbeLoop();
#elif BOARD_LCD_SWEEP_MODE
  BOARD_LCD_ForceBacklightDefaultState();
  BOARD_LCD_SweepLoop();
#else
  /* Start ADC DMA Continuous Conversion */
  if (HAL_ADC_Start_DMA(&hadc1, (uint32_t*)&g_adc_dma_buffer, ADC_DMA_BUFFER_SIZE) != HAL_OK)
  {
    Error_Handler();
  }
  
  /* Start TIM3 for non-blocking system timing (1ms base) */
  if (HAL_TIM_Base_Start_IT(&htim3) != HAL_OK)
  {
    Error_Handler();
  }
  
  if (HAL_TIM_PWM_Start(&htim1, TIM_CHANNEL_1) != HAL_OK)
  {
    Error_Handler();
  }
  if (HAL_TIM_PWM_Start(&htim4, TIM_CHANNEL_1) != HAL_OK)
  {
    Error_Handler();
  }
  if (HAL_TIM_PWM_Start(&htim4, TIM_CHANNEL_2) != HAL_OK)
  {
    Error_Handler();
  }
  System_Init();
  MX_USB_DEVICE_Init();
#if BOARD_IRRIGATION_DEMO_MODE
  BOARD_IrrigationDemoInit();
#endif
#endif

  /* USER CODE END 2 */

  /* Infinite loop */
  /* USER CODE BEGIN WHILE */
  
  /* Test: Blink LED to verify code is running */
  uint32_t led_tick = 0;
  
  while (1)
  {
    /* USER CODE END WHILE */

    /* Test LED blink - PC13 */
    if ((HAL_GetTick() - led_tick) >= 500U) {
      led_tick = HAL_GetTick();
      HAL_GPIO_TogglePin(GPIOC, GPIO_PIN_13);
    }

    if ((HAL_GetTick() - last_task_tick) >= SYSTEM_TASK_PERIOD_MS) {
      last_task_tick = HAL_GetTick();
      System_CommunicationTask();
      System_HMITask();
      System_ProgramManagementTask();
      System_IrrigationTask();
      System_MaintenanceTask();
      LOW_POWER_CheckAutoSleep();

      validation_counter++;
      if (validation_counter >= SYSTEM_VALIDATION_INTERVAL) {
        validation_counter = 0U;
        System_SafetyMonitoringTask();
      }
    }

#if BOARD_IRRIGATION_DEMO_MODE
    BOARD_IrrigationDemoProcess();
#endif

    if ((HAL_GetTick() - last_status_update) >= SYSTEM_STATUS_PERIOD_MS) {
      last_status_update = HAL_GetTick();
      System_Status_Update();
    }
  }
  /* USER CODE END 3 */
}

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
/* USER CODE BEGIN 4 */

/* DMA and Interrupt Callbacks =================================================*/

/**
 * @brief TIM3 Update Interrupt Callback (System Tick - 1ms)
 */
void HAL_TIM_PeriodElapsedCallback(TIM_HandleTypeDef *htim)
{
  if (htim->Instance == TIM3)
  {
    g_system_tick++;
    VALVES_TimerTick1ms();
  }
}

/* USER CODE END 4 */

/**
 * @brief TIM2 Initialization (Buzzer PWM)
 */
static void MX_TIM2_Init(void)
{
  TIM_ClockConfigTypeDef sClockSourceConfig = {0};
  TIM_MasterConfigTypeDef sMasterConfig = {0};
  TIM_OC_InitTypeDef sConfigOC = {0};

  htim2.Instance = TIM2;
  htim2.Init.Prescaler = 83;  /* 168MHz / 84 = 2MHz (1MHz PWM) */
  htim2.Init.CounterMode = TIM_COUNTERMODE_UP;
  htim2.Init.Period = 999;    /* 1kHz PWM frequency */
  htim2.Init.ClockDivision = TIM_CLOCKDIVISION_DIV1;
  htim2.Init.AutoReloadPreload = TIM_AUTORELOAD_PRELOAD_ENABLE;
  if (HAL_TIM_Base_Init(&htim2) != HAL_OK)
  {
    Error_Handler();
  }
  sClockSourceConfig.ClockSource = TIM_CLOCKSOURCE_INTERNAL;
  if (HAL_TIM_ConfigClockSource(&htim2, &sClockSourceConfig) != HAL_OK)
  {
    Error_Handler();
  }
  if (HAL_TIM_PWM_Init(&htim2) != HAL_OK)
  {
    Error_Handler();
  }
  sMasterConfig.MasterOutputTrigger = TIM_TRGO_RESET;
  sMasterConfig.MasterSlaveMode = TIM_MASTERSLAVEMODE_DISABLE;
  if (HAL_TIMEx_MasterConfigSynchronization(&htim2, &sMasterConfig) != HAL_OK)
  {
    Error_Handler();
  }
  sConfigOC.OCMode = TIM_OCMODE_PWM1;
  sConfigOC.Pulse = 0;
  sConfigOC.OCPolarity = TIM_OCPOLARITY_HIGH;
  sConfigOC.OCFastMode = TIM_OCFAST_DISABLE;
  if (HAL_TIM_PWM_ConfigChannel(&htim2, &sConfigOC, TIM_CHANNEL_1) != HAL_OK)
  {
    Error_Handler();
  }
  HAL_TIM_MspPostInit(&htim2);
}

/**
 * @brief TIM3 Initialization (System Time Base - 1ms)
 */
static void MX_TIM3_Init(void)
{
  TIM_ClockConfigTypeDef sClockSourceConfig = {0};
  TIM_MasterConfigTypeDef sMasterConfig = {0};

  htim3.Instance = TIM3;
  htim3.Init.Prescaler = 8399;  /* 84MHz / 8400 = 10kHz */
  htim3.Init.CounterMode = TIM_COUNTERMODE_UP;
  htim3.Init.Period = 9;        /* 10kHz / 10 = 1kHz (1ms) */
  htim3.Init.ClockDivision = TIM_CLOCKDIVISION_DIV1;
  htim3.Init.AutoReloadPreload = TIM_AUTORELOAD_PRELOAD_ENABLE;
  if (HAL_TIM_Base_Init(&htim3) != HAL_OK)
  {
    Error_Handler();
  }
  sClockSourceConfig.ClockSource = TIM_CLOCKSOURCE_INTERNAL;
  if (HAL_TIM_ConfigClockSource(&htim3, &sClockSourceConfig) != HAL_OK)
  {
    Error_Handler();
  }
  sMasterConfig.MasterOutputTrigger = TIM_TRGO_RESET;
  sMasterConfig.MasterSlaveMode = TIM_MASTERSLAVEMODE_DISABLE;
  if (HAL_TIMEx_MasterConfigSynchronization(&htim3, &sMasterConfig) != HAL_OK)
  {
    Error_Handler();
  }
}

/**
 * @brief TIM4 Initialization (Dosing Hardware PWM - PB6/PB7)
 */
static void MX_TIM4_Init(void)
{
  TIM_ClockConfigTypeDef sClockSourceConfig = {0};
  TIM_MasterConfigTypeDef sMasterConfig = {0};
  TIM_OC_InitTypeDef sConfigOC = {0};

  htim4.Instance = TIM4;
  htim4.Init.Prescaler = 8399;  /* 84MHz / 8400 = 10kHz */
  htim4.Init.CounterMode = TIM_COUNTERMODE_UP;
  htim4.Init.Period = 399;      /* 10kHz / 400 = 25Hz */
  htim4.Init.ClockDivision = TIM_CLOCKDIVISION_DIV1;
  htim4.Init.AutoReloadPreload = TIM_AUTORELOAD_PRELOAD_ENABLE;
  if (HAL_TIM_Base_Init(&htim4) != HAL_OK)
  {
    Error_Handler();
  }
  sClockSourceConfig.ClockSource = TIM_CLOCKSOURCE_INTERNAL;
  if (HAL_TIM_ConfigClockSource(&htim4, &sClockSourceConfig) != HAL_OK)
  {
    Error_Handler();
  }
  if (HAL_TIM_PWM_Init(&htim4) != HAL_OK)
  {
    Error_Handler();
  }
  sMasterConfig.MasterOutputTrigger = TIM_TRGO_RESET;
  sMasterConfig.MasterSlaveMode = TIM_MASTERSLAVEMODE_DISABLE;
  if (HAL_TIMEx_MasterConfigSynchronization(&htim4, &sMasterConfig) != HAL_OK)
  {
    Error_Handler();
  }
  sConfigOC.OCMode = TIM_OCMODE_PWM1;
  sConfigOC.Pulse = 0;
  sConfigOC.OCPolarity = TIM_OCPOLARITY_HIGH;
  sConfigOC.OCFastMode = TIM_OCFAST_DISABLE;
  if (HAL_TIM_PWM_ConfigChannel(&htim4, &sConfigOC, TIM_CHANNEL_1) != HAL_OK)
  {
    Error_Handler();
  }
  if (HAL_TIM_PWM_ConfigChannel(&htim4, &sConfigOC, TIM_CHANNEL_2) != HAL_OK)
  {
    Error_Handler();
  }
  HAL_TIM_MspPostInit(&htim4);
}

/**
 * @brief CRC Initialization (Hardware CRC for data validation)
 * @note Stubbed - HAL CRC driver not available
 */
static void MX_CRC_Init(void)
{
  /* CRC initialization stubbed - driver not available in this build */
  /* Full implementation requires stm32f4xx_hal_crc.c */
}

/**
 * @brief RTC Initialization (Real-time clock for scheduling)
 * @note Stubbed - HAL RTC driver not available
 */
static void MX_RTC_Init(void)
{
  /* RTC initialization stubbed - driver not available in this build */
  /* Full implementation requires stm32f4xx_hal_rtc.c */
}

/* USER CODE END 4 */
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


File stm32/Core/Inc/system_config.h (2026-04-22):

/**
 ******************************************************************************
 * @file           : system_config.h
 * @brief          : Sistem konfigürasyon ayarları
 ******************************************************************************
 */

#ifndef __SYSTEM_CONFIG_H
#define __SYSTEM_CONFIG_H

#ifdef __cplusplus
extern "C" {
#endif

/* Includes ------------------------------------------------------------------*/
#include <stdbool.h>
#include <stdint.h>

/* System Clock Configuration -----------------------------------------------*/
/* HSE_VALUE is defined in stm32f4xx_hal_conf.h */
#define HSE_BYPASS 0U
#define CLOCK_SOURCE RCC_PLLSOURCE_HSE
#define SYSCLK_FREQ 168000000U      /* 168 MHz System Clock */
#define HCLK_FREQ SYSCLK_FREQ       /* AHB Clock */
#define PCLK1_FREQ (HCLK_FREQ / 4U) /* APB1 Clock (42 MHz) */
#define PCLK2_FREQ (HCLK_FREQ / 2U) /* APB2 Clock (84 MHz) */

/* Memory Map ----------------------------------------------------------------*/
/* FLASH_BASE and SRAM_BASE are defined in CMSIS device header */
#define FLASH_SIZE 512U /* 512 KB */
#define SRAM_SIZE 192U  /* 192 KB */

/* Interrupt Priorities -----------------------------------------------------*/
#define NVIC_PRIORITYGROUP NVIC_PRIORITYGROUP_4

#define TOUCH_IRQ_PRIORITY 0U /* En yüksek öncelik */
#define ADC_IRQ_PRIORITY 1U
#define TIM3_IRQ_PRIORITY 2U
#define USART1_IRQ_PRIORITY 3U
#define I2C1_IRQ_PRIORITY 4U

/* Tick Configuration -------------------------------------------------------*/
#define SYSTICK_PERIOD_MS 1U
#define SYSTICK_FREQ 1000U /* 1 kHz */

/* Watchdog Configuration ---------------------------------------------------*/
#define IWDG_TIMEOUT_MS 2000U /* 2 saniye */
#define WWDG_TIMEOUT_MS 500U  /* 500 ms */

/* Debug Configuration ------------------------------------------------------*/
#define DEBUG_ENABLED 1U
#define DEBUG_UART USART1
#define DEBUG_BAUDRATE 115200U

/* Board bring-up diagnostics -----------------------------------------------*/
/*
 * This board exposes visible user LEDs on PA6/PA7. Enable this mode to build
 * a minimal firmware that only blinks D2/D3 so we can confirm the MCU is
 * executing code during board bring-up.
 */
#define BOARD_LED_DIAGNOSTIC_MODE 0U

/*
 * Minimal TFT test mode. Only initializes the LCD path and cycles solid colors
 * on the screen, which helps isolate FSMC/panel issues from the full app.
 */
#define BOARD_LCD_TEST_MODE 0U

/*
 * LCD probe mode. Reads controller ID/status registers and leaves the raw
 * values in RAM so we can inspect them over SWD without needing UART output.
 */
#define BOARD_LCD_PROBE_MODE 0U

/*
 * LCD sweep mode. Tries a set of common 320x240 parallel-TFT controller/init
 * combinations and control-line assumptions so we can identify a working
 * profile just by watching the panel.
 */
#define BOARD_LCD_SWEEP_MODE 0U

/*
 * Short irrigation demo. Runs a one-shot valve sequence after boot so we can
 * verify the output stages and GUI updates without relying on sensor inputs.
 */
#define BOARD_IRRIGATION_DEMO_MODE 0U

/*
 * Sensor demo mode. Replaces live pH/EC readings with a small looping profile
 * so we can exercise the main screen without depending on external probes.
 */
#define BOARD_SENSOR_DEMO_MODE 1U

/* Cooperative task scheduler -----------------------------------------------*/
#define SYSTEM_TASK_PERIOD_MS 100U
#define SYSTEM_VALIDATION_INTERVAL 10U
#define SYSTEM_SENSOR_STALE_TIMEOUT_MS 3000U
#define SYSTEM_MAINTENANCE_PERIOD_MS 1000U
#define SYSTEM_STATUS_PERIOD_MS 250U
#define SYSTEM_RUNTIME_SNAPSHOT_PERIOD_MS 2000U
#define SYSTEM_SCHEDULE_GUARD_MINUTE 1U

/* Version Information ------------------------------------------------------*/
#define FIRMWARE_VERSION_MAJOR 0U
#define FIRMWARE_VERSION_MINOR 1U
#define FIRMWARE_VERSION_PATCH 0U
#define FIRMWARE_VERSION "0.1.0"
#define FIRMWARE_BUILD_DATE __DATE__
#define FIRMWARE_BUILD_TIME __TIME__

/* System Status Flags ------------------------------------------------------*/
typedef struct {
  uint8_t system_ready;
  uint8_t ph_sensor_ok;
  uint8_t ec_sensor_ok;
  uint8_t lcd_ok;
  uint8_t touch_ok;
  uint8_t eeprom_ok;
  uint8_t rtc_ok;
  uint8_t eeprom_crc_ok;
  uint8_t error_code;
  char alarm_text[32];
} SystemStatus_t;

extern SystemStatus_t gSystemStatus;

/* Function Prototypes ------------------------------------------------------*/
void System_Init(void);
void System_Status_Update(void);
void System_CommunicationTask(void);
void System_HMITask(void);
void System_ProgramManagementTask(void);
void System_IrrigationTask(void);
void System_SafetyMonitoringTask(void);
void System_MaintenanceTask(void);

#ifdef __cplusplus
}
#endif

#endif /* __SYSTEM_CONFIG_H */

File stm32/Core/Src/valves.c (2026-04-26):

/**
 ******************************************************************************
 * @file           : valves.c
 * @brief          : Vana Kontrol Driver (PCF8574 I2C Expander ile)
 ******************************************************************************
 */

#include "main.h"
#include "valves.h"
#include "pcf8574.h"
#include <string.h>
#include <stdio.h>

/* External I2C Handle */
extern I2C_HandleTypeDef hi2c1;
extern TIM_HandleTypeDef htim4;

/* SYSTEM_Log fonksiyonları yoksa define et */
#ifndef SYSTEM_LogInfo
#define SYSTEM_LogInfo(...)  ((void)0)
#endif
#ifndef SYSTEM_LogError
#define SYSTEM_LogError(...) ((void)0)
#endif
#ifndef SYSTEM_LogWarn
#define SYSTEM_LogWarn(...)  ((void)0)
#endif
#ifndef GUI_ShowError
#define GUI_ShowError(...)   ((void)0)
#endif

/* Global Valve Data --------------------------------------------------------*/
static valve_t g_valves[TOTAL_VALVE_COUNT] = {0};
static parcel_t g_parcels[PARCEL_VALVE_COUNT] = {0};
typedef struct {
  GPIO_TypeDef *port;
  uint16_t pin;
  TIM_HandleTypeDef *pwm_timer;
  uint32_t pwm_channel;
  uint8_t hardware_pwm;
  uint8_t frequency_hz;
  uint8_t min_duty_percent;
  uint8_t max_duty_percent;
  uint8_t target_duty_percent;
  uint8_t applied_duty_percent;
  uint8_t ramp_step_percent;
  uint8_t enabled;
  uint8_t output_state;
  uint16_t period_ticks;
  uint16_t on_ticks;
  uint16_t tick_in_period;
} dosing_pwm_channel_t;

static dosing_pwm_channel_t g_dosing_pwm[DOSING_VALVE_COUNT] = {
    {
        .port = DOSING_ACID_PORT,
        .pin = DOSING_ACID_PIN,
        .pwm_timer = &htim4,
        .pwm_channel = TIM_CHANNEL_1,
        .hardware_pwm = 1U,
        .frequency_hz = DOSING_HW_PWM_FREQ_HZ,
        .min_duty_percent = DOSING_PWM_DEFAULT_MIN_DUTY,
        .max_duty_percent = DOSING_PWM_DEFAULT_MAX_DUTY,
        .target_duty_percent = DOSING_PWM_DEFAULT_DUTY,
        .ramp_step_percent = DOSING_PWM_DEFAULT_RAMP_STEP,
        .period_ticks = 40U,
    },
    {
        .port = DOSING_FERT_A_PORT,
        .pin = DOSING_FERT_A_PIN,
        .pwm_timer = &htim4,
        .pwm_channel = TIM_CHANNEL_2,
        .hardware_pwm = 1U,
        .frequency_hz = DOSING_HW_PWM_FREQ_HZ,
        .min_duty_percent = DOSING_PWM_DEFAULT_MIN_DUTY,
        .max_duty_percent = DOSING_PWM_DEFAULT_MAX_DUTY,
        .target_duty_percent = DOSING_PWM_DEFAULT_DUTY,
        .ramp_step_percent = DOSING_PWM_DEFAULT_RAMP_STEP,
        .period_ticks = 40U,
    },
    {
        .port = DOSING_FERT_B_PORT,
        .pin = DOSING_FERT_B_PIN,
        .frequency_hz = DOSING_FERT_PWM_DEFAULT_FREQ_HZ,
        .min_duty_percent = DOSING_PWM_DEFAULT_MIN_DUTY,
        .max_duty_percent = DOSING_PWM_DEFAULT_MAX_DUTY,
        .target_duty_percent = DOSING_PWM_DEFAULT_DUTY,
        .ramp_step_percent = DOSING_PWM_DEFAULT_RAMP_STEP,
        .period_ticks = 40U,
    },
    {
        .port = DOSING_FERT_C_PORT,
        .pin = DOSING_FERT_C_PIN,
        .frequency_hz = DOSING_FERT_PWM_DEFAULT_FREQ_HZ,
        .min_duty_percent = DOSING_PWM_DEFAULT_MIN_DUTY,
        .max_duty_percent = DOSING_PWM_DEFAULT_MAX_DUTY,
        .target_duty_percent = DOSING_PWM_DEFAULT_DUTY,
        .ramp_step_percent = DOSING_PWM_DEFAULT_RAMP_STEP,
        .period_ticks = 40U,
    },
    {
        .port = DOSING_FERT_D_PORT,
        .pin = DOSING_FERT_D_PIN,
        .frequency_hz = DOSING_FERT_PWM_DEFAULT_FREQ_HZ,
        .min_duty_percent = DOSING_PWM_DEFAULT_MIN_DUTY,
        .max_duty_percent = DOSING_PWM_DEFAULT_MAX_DUTY,
        .target_duty_percent = DOSING_PWM_DEFAULT_DUTY,
        .ramp_step_percent = DOSING_PWM_DEFAULT_RAMP_STEP,
        .period_ticks = 40U,
    },
};

/* Safety & Validation ------------------------------------------------------*/
static uint16_t g_valve_command_crc = 0U;
static uint32_t g_last_command_time = 0U;
static uint8_t g_consecutive_faults = 0U;
static uint8_t g_expected_state[TOTAL_VALVE_COUNT] = {0};
static uint8_t g_error_mask = 0U;

/* Private Function Prototypes ----------------------------------------------*/
static void VALVES_UpdateState(uint8_t id, valve_state_t new_state);
static uint8_t VALVES_IsValidValveId(uint8_t valve_id);
static uint8_t VALVES_GetPCFChip(uint8_t valve_id);
static uint8_t VALVES_GetPCFPin(uint8_t valve_id);
static uint16_t VALVES_CalculateCommandCRC(void);
static int8_t VALVES_GetDosingIndex(uint8_t valve_id);
static void VALVES_WriteDosingOutput(uint8_t dosing_index, GPIO_PinState state);
static void VALVES_ApplyHardwareDosingPWM(uint8_t dosing_index);
static uint8_t VALVES_ClampDosingDuty(const dosing_pwm_channel_t *channel,
                                      uint8_t duty_percent);
static void VALVES_RefreshDosingTiming(uint8_t dosing_index);
static void VALVES_StepDosingRamp(uint8_t dosing_index);
static void VALVES_RecordFault(uint8_t valve_id, uint8_t fault_flag);
static void VALVES_ClearFault(uint8_t valve_id, uint8_t fault_flag);
static void VALVES_ClearAllValveFaults(uint8_t fault_flag);
static void VALVES_CloseOtherParcelValves(uint8_t keep_open_valve_id);
static void VALVES_ApplyDosingInterlock(uint8_t valve_id);
static uint8_t VALVES_ShouldEmulateParcelOutputs(void);
static void VALVES_MarkParcelValveOpened(uint8_t valve_id);
static void VALVES_MarkParcelValveClosed(uint8_t valve_id, uint32_t now);
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

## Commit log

2026-03-16 Add STM32CubeIDE project files
2026-03-16 feat: Implement Modbus communication for sensors, refactor sensor reading, and add irrigation control functions.
2026-03-17 feat: Implement fallback font rendering with display dimension awareness, add valve mode control, and create TODO file.
2026-03-17 Make irrigation control non-blocking and clean sensor warnings
2026-03-17 Implement non-blocking dosing timers and add hardware test checklist
2026-03-26 feat:STM32F4VE kart şeması
2026-04-22 Add USB programmer GUI for irrigation program parameters
    - Implemented a Tkinter-based GUI for managing irrigation programs via USB.
    - Added functionality to discover USB ports and connect to selected port.
    - Included features to read, save, and edit irrigation program configurations.
    - Implemented input validation for program parameters.
    - Added logging functionality to track operations and errors.
    [buzzer.c, buzzer.h, eeprom.c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]
2026-04-26 Stabilize field control MVP
    [Irrigation_Venturi_Pulse_40m3h.FCStd, Irrigation_Venturi_Pulse_40m3h.step, Printable_throat_insert_22mm.stl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]
2026-04-26 Refactor code structure for improved readability and maintainability
    [Irrigation_Venturi_Pulse_40m3h.FCStd]
2026-04-27 Add optimized Modbus RTU implementation for PIC18F86K22
    - Implemented modbus_optimized.c with modular structure and performance enhancements.
    - Added CRC16 calculation without lookup tables to save ROM.
    - Created modbus_optimized.h header file for configuration constants and function declarations.
    - Included error handling for Modbus function codes and improved buffer management.
    - Optimized UART communication handling for master and slave modes.
    - Enhanced timer management for better timeout handling and CPU activity indication.
    [buzzer.c, buzzer.h, dosing_controller.c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]

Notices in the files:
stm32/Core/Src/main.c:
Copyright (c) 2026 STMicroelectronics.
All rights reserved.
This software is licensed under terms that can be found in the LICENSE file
